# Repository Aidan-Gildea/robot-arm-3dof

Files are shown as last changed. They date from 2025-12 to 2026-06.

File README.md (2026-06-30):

# Hubert — 3-DOF Robotic Manipulator

**Inverse Kinematics–driven motion planning with Python & Arduino, built for ~$100.**

*Designed, programmed, and assembled as a self-directed learning project.*

---

## Demo Videos

| Path Tracing Demo | Hardware Overview | Project Presentation |
|---|---|---|
| Path Tracing (https://youtu.be/4sgCwkX76dg?si=9VvJAM_YSKhd0c1-) | Hardware Overview (https://youtu.be/wcLp37mRvIc?si=lRgipF_aaHsbhIL2) | Project Presentation (https://youtu.be/JEB1u3Z_pXA?si=sM1r-wsa0qPkrcNg) |
| Hubert traces a scripted 3D semi-circle path. | Walk-through of the mechanical and electrical design. | Full project presentation and live demo. |

---

## Project Overview

Hubert is a **3-Degree-of-Freedom (3-DOF) robotic manipulator** capable of precise end-effector positioning from Cartesian coordinate inputs. The arm features three revolute joints (base rotation, shoulder, and elbow) plus a two-finger servo gripper, all driven by a custom **Inverse Kinematics solver that I derived from first principles** using algebra and geometry.

I started this project as a 10th-grade student with almost no prior experience in robotics. I chose to build a manipulator arm because the future of robotics is trending toward humanoid platforms, and an articulated arm is a natural entry point for developing core competencies in mechanical design, embedded systems, and motion planning.

### Barriers Overcome

- **Cost.** The entire project was completed for approximately **$100** in parts and tooling (excluding a 3D printer), making it accessible without institutional funding.
- **Self-taught curriculum.** With no structured coursework available, I taught myself 3D CAD modeling (Fusion 360), electronics (wiring, PWM, I²C), and programming (C++, Python, serial communication) through YouTube tutorials and online documentation—learning as I built.

---

## Bill of Materials

| Category | Component | Function |
|---|---|---|
| Microcontroller | [Arduino Uno R3](https://www.amazon.com/ELEGOO-Board-ATmega328P-ATMEGA16U2-Compliant/dp/B01EWOE0UU) | Low-level control & serial I/O  |
| Actuators | [5× MG996R Servos](https://www.amazon.com/4-Pack-MG996R-Torque-Digital-Helicopter/dp/B07MFK266B) (4-pack + 1) | High-torque joint & gripper actuation |
| Servo Driver | [PCA9685 16-Channel PWM Driver](https://www.amazon.com/HUAREW-PCA9685-Interface-Compatible-Raspberry/dp/B0CRV3MK14) | Dedicated PWM generation via I²C |
| Power Supply | [Adjustable DC Module](https://www.amazon.com/Adjustable-Switching-Regulated-Adjustments-Jesverty/dp/B09YSJQWRG) | Isolated 5–6 V servo power rail |
| Fasteners | [M2.5/M3 Phillips Screws](https://www.amazon.com/NINDEJIN-Countersunk-Replacement-Electronic-Accessories/dp/B0B5CY5LY5) | Structural assembly |
| Fasteners | [M2.5/M3 Threaded Heat-Set Inserts](https://www.amazon.com/Ktehloy-Threaded-Assortment-Printing-Components/dp/B0CLKDPN65)  | Durable screw receptacles in 3D prints |
| Supports | Standard ball bearings | Low-friction joint rotation |

> **Note:** Purchase links are provided for convenience and may expire over time. The full 3D-printable assembly is available at `Hardware/CAD/Full Assembly.step`. A detailed parts list is also in `Hardware/BOM.csv`.

---

## System Architecture

```
┌──────────────────────┐       USB / Serial        ┌──────────────────────┐
│   Host Computer      │      (9600 baud)          │   Arduino Uno        │
│                      │ ─────────────────────────▶ │                      │
│  Python              │   "base j1 j2 g1 g2\n"   │  main.cpp            │
│  ├─ kinematics.py    │                           │  ├─ Serial parser    │
│  ├─ controller.py    │                           │  └─ motors.cpp       │
│  └─ fun_path.py      │                           │      ├─ PCA9685 I²C  │
│                      │                           │      └─ Servo PWM    │
└──────────────────────┘                           └──────────┬───────────┘
                                                              │ I²C
                                                   ┌──────────▼───────────┐
                                                   │  PCA9685 PWM Driver  │
                                                   │  (16 channels)       │
                                                   └──┬──┬──┬──┬──┬──────┘
                                                      │  │  │  │  │
                                                   Servo1─5 (MG996R)
```

The host computer runs the IK solver and sends joint angles over serial. The Arduino parses incoming commands and forwards pulse-width values to the PCA9685, which generates 50 Hz PWM signals for each servo.

---

## Inverse Kinematics

The IK solver lives in `RobotArmKinematics/kinematics.py` and converts a Cartesian target $(x, y, z)$ into three joint angles. This is the core piece of math that makes the arm useful—without it, you would need to manually compute angles for every desired position.

### Arm Geometry

| Parameter | Value |
|---|---|
| Base link height | 50 mm |
| Link 1 (shoulder → elbow) | 110 mm  |
| Link 2 (elbow → end-effector) | 71 mm |
| Max theoretical reach | 181 mm  |
| General servo offset | 60° |

### Algorithm

The solver performs the following steps. All intermediate calculations use radians; outputs are converted to integer degrees.

1. **Subtract base height.** The target $y$ coordinate is reduced by the base link height (50 mm) to shift the origin to the shoulder joint.

2. **Project onto the XZ plane.** Compute the horizontal radius:

$$r = \sqrt{x^2 + z^2}$$

3. **Enforce physical constraints.** Reject the target if $z < 0$ (below the ground plane).

4. **Base rotation angle.** Using the Law of Cosines on the projected circle, compute the base angle relative to the positive X-axis. The angle is then normalized to $[0°, 180°]$ to match servo limits.

5. **Joint 1 (shoulder).** Compute the planar distance from the shoulder to the target:

$$a_3 = \sqrt{x_{\text{proj}}^2 + y_{\text{proj}}^2}$$

Then solve using:

$$\theta_1 = \text{atan2}(y_{\text{proj}},\; x_{\text{proj}}) + \arccos\!\left(\frac{L_1^2 + a_3^2 - L_2^2}{2 \cdot L_1 \cdot a_3}\right) + \text{offset}$$

6. **Joint 2 (elbow).** Apply the Law of Cosines to the triangle formed by $L_1$, $L_2$, and $a_3$:

$$\theta_2 = \arccos\!\left(\frac{L_1^2 + L_2^2 - a_3^2}{2 \cdot L_1 \cdot L_2}\right) - 90° + \text{offset}$$

7. **Clamp and validate.** All three angles are checked against $[0°, 180°]$. If any fall outside this range, the target is deemed unreachable and the function returns `False`.

### Workspace Analysis

The script `RobotArmKinematics/workspace_test.py` performs a brute-force reachability scan over a 3D grid (default step size: 10 mm) and exports all valid $(x, y, z) \rightarrow (\theta_{\text{base}}, \theta_1, \theta_2)$ mappings to `workspace_results.json`. This is useful for visualizing the arm's true working envelope and identifying dead zones.

---

## Software

Hubert's software is split into two layers, mirroring the physical separation between the host computer and the onboard microcontroller.

### Host-Side — Python

The Python programs run on the host computer and handle kinematics, user input, and serial transmission.

| File | Purpose |
|---|---|
| `kinematics.py` | Core IK solver — `IK()` function and `distance_formula()` helper. |
| `controller.py` | **Real-time Pygame controller.** Arrow keys for XY, F/B for Z, Space to toggle gripper, R to home. Includes a rate-limited command loop (50 ms) and a visual GUI overlay. |
| `fun_path.py` | Scripted path demonstration — traces a semi-circle at two heights with smooth transitions. Used in the demo video. |
| `communication.py`  | Minimal serial test — sends a homing command to verify connectivity. |
| `workspace_test.py` | Brute-force 3D reachability scan, exports results to JSON. |

**Controller key bindings:**

| Key | Action |
|---|---|
| ↑ / ↓ | Move Y (vertical) |
| ← / → | Move X (horizontal) |
| F / B | Move Z (depth) |
| Space | Toggle gripper |
| R | Reset to home |
| Esc | Quit |

### Firmware — C++ / PlatformIO

The firmware runs on the Arduino Uno and is managed with [PlatformIO](https://platformio.org/).

| File | Purpose |
|---|---|
| `main.cpp` | Serial read loop — accumulates bytes, tokenizes on spaces, parses 5 integers, dispatches to motor driver. |
| `motors.cpp` | PCA9685 initialization, angle → pulse mapping with per-servo calibration offsets, homing routine, analog feedback reading. |
| `motors.h` | Constants (pulse range 145–560, 50 Hz, channel addresses, per-servo offsets) and function declarations. |
| `communication.cpp`| Legacy text-command parser (SERVO, HOME, HELP, ANGLE). Currently disabled — preserved for future re-integration. |

**Homing behavior:** On startup, all servos are driven to 90° (mid-range). Joints 1 and 2 additionally receive a 60° general offset to position the arm upright, maximizing the usable range of motion.

---

## Getting Started

### Prerequisites

- **Hardware:** Assemble per the BOM above. Wire the PCA9685 to the Arduino via I²C (SDA → A4, SCL → A5). Power servos from the adjustable DC supply (set to 5–6 V), **not** from the Arduino's 5 V rail.
- **Firmware toolchain:** [PlatformIO](https://platformio.org/) (VS Code extension or CLI).
- **Python 3.8+** with `pip`.

### Flash the Firmware

```bash
# From the repository root
pio run --target upload
```

### Install Python Dependencies

```bash
pip install numpy pyserial pygame
```

### Run the Controller

```bash
cd RobotArmKinematics
python controller.py
```

> **Important:** Set the `PORT` variable at the top of the Python script to match your Arduino's COM port (e.g., `COM6` on Windows, `/dev/ttyACM0` on Linux).

---

## Serial Protocol

Commands are sent as **5 space-separated integers** (each 0–180) followed by a newline:

```
90 150 150 50 130\n
```

The five values correspond to: base rotation, joint 1, joint 2, gripper finger A, gripper finger B. The Arduino's 30-byte input buffer supports commands up to 24 characters.

For a detailed walkthrough of the byte-level parsing, tokenization, and execution pipeline, see [PROTOCOL.md](PROTOCOL.md).

---

## Repository Structure

```
robot-arm-3dof/
├── platformio.ini              # PlatformIO build configuration
├── README.md
├── PROTOCOL.md                 # Detailed serial protocol documentation
├── Hardware/
│   ├── BOM.csv                 # Bill of materials with purchase links
│   └── CAD/
│       └── Full Assembly.step  # Complete 3D CAD assembly
├── include/
│   └── motors.h                # Servo constants, channel map, declarations
├── src/
│   ├── main.cpp                # Serial reader and command dispatcher
│   ├── motors.cpp              # PCA9685 driver, homing, offset calibration
│   └── communication.cpp       # Legacy command parser (disabled)
├── RobotArmKinematics/
│   ├── kinematics.py           # Inverse kinematics solver
│   ├── controller.py           # Pygame real-time controller
│   ├── fun_path.py             # Scripted path demonstration
│   ├── communication.py        # Minimal serial connectivity test
│   ├── workspace_test.py       # 3D reachability analysis
│   ├── workspace_results.json  # Exported reachability data
│   └── requirements.txt        # Python dependencies
├── lib/                        # PlatformIO library folder
└── test/                       # PlatformIO test folder
```

---

## Future Work

- **Closed-loop control.** The analog feedback pins (A0–A5) are already wired; implementing PID-based position verification would improve accuracy under load.
- **Computer vision integration.** Object detection via a camera feed to enable autonomous pick-and-place tasks.
- **Re-enable command parser.** Restore the text-based command interface in `communication.cpp` for interactive debugging alongside the IK pipeline.

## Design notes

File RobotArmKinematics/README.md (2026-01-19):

#Kinematics
This the kinematics folder for my project. it contains: 
fun_path.py - a short, ~10 sec demonstration of the robot following a path using my custom Inverse Kinematics function. 
communication.py - a demonstration of sending angle data based off of a single point
kinematics.py - the container for my inverse kinematics function

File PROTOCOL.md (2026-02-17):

# Serial Communication Protocol

The robot arm receives servo angle commands via serial communication at **9600 baud** over USB.

---

## Command Format

Send **5 space-separated integers** (each 0–180) followed by a newline character:

```
base joint1 joint2 gripper1 gripper2\n
```

**Example — home position:**

```
90 150 150 90 90
```

Each integer maps to a servo channel on the PCA9685 driver:

| Position | Servo | PCA9685 Channel | Role |
|---|---|---|---|
| 1 | Base | 0 | Base rotation |
| 2 | Joint 1 | 1 | Shoulder |
| 3 | Joint 2 | 2 | Elbow |
| 4 | Gripper A | 4 | Gripper finger  |
| 5 | Gripper B | 6 | Gripper finger  |

---

## How the Byte Reading Works

The serial reader in `main.cpp` processes incoming bytes one at a time to parse angle commands.

### 1. Byte-by-Byte Accumulation

```cpp
static byte currIndex = 0;   // Persists across loop() calls
char inByte = Serial.read();  // Read one byte at a time
```

Each character is stored in `inputLine[]` until a newline (`\n`) is received:

| Byte # | Character | Buffer State |
|---|---|---|
| 1 | `'9'` | `"9"` |
| 2 | `'0'` | `"90"` |
| 3 | `' '` | `"90 "` |
| 4 | `'4'` | `"90 4"` |
| ... | ... | ... |
| n | `'\n'` | Process! |

### 2. Tokenization

When a newline is received, spaces are replaced with null terminators (`\0`):

```
Before: "90 45 60 30 120\0"
After:  "90\045\060\030\0120\0"
```

This creates **5 separate C-strings** in contiguous memory.

### 3. Parsing

A pointer walks through the buffer, converting each token to an integer:

```cpp
char* ptr = inputLine;
for (int i = 0; i < 5; i++) {
    angles[i] = atoi(ptr);        // Convert string to int
    ptr += strlen(ptr) + 1;       // Jump to next token
}
```

### 4. Execution

The parsed angles are passed to `ServosSetAngles()`, which:

1. **Validates** each angle is within `[0, 180]`.
2. **Maps** each angle to a PWM pulse length using the formula:
   ```
   pulse = map(angle, 0, 180, SERVOMIN, SERVOMAX)
   ```
   where `SERVOMIN = 145` and `SERVOMAX = 560` (out of 4096 ticks at 50 Hz).
3. **Applies** per-servo calibration offsets to compensate for hardware misalignment.
4. **Writes** the final pulse to the corresponding PCA9685 channel via I²C.

---

## Buffer Limits

| Parameter | Value |
|---|---|
| Max input length | 30 bytes |
| Max valid command | `"180 180 180 180 180\n"` = 24 chars  |
| Baud rate | 9600 |
| Line terminator | `\n` (newline) |

---

## Per-Servo Calibration Offsets

Each servo has an individual angular offset defined in `motors.h` to correct for mechanical misalignment:

| Servo | Offset |
|---|---|
| Base | +10° |
| Joint 1 | −10° |
| Joint 2 | −5° |
| Gripper A | +10° |
| Gripper B | −10° |

These offsets are converted from degrees to pulse-length deltas and applied after the angle-to-pulse mapping. Additionally, joints 1 and 2 receive a **general offset of 60°** (converted to pulse length) during the homing routine to increase their effective range of motion.

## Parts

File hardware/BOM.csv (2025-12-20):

Item | Purchase Link
M2.5/M3 Phillips screw kit | https://www.amazon.com/NINDEJIN-Countersunk-Replacement-Electronic-Accessories/dp/B0B5CY5LY5
MG996R servo motors (4-pack) | https://www.amazon.com/4-Pack-MG996R-Torque-Digital-Helicopter/dp/B07MFK266B?sp_csd=d2lkZ2V0TmFtZT1zcF9hdGY
PCA9685 16-channel PWM driver | https://www.amazon.com/HUAREW-PCA9685-Interface-Compatible-Raspberry/dp/B0CRV3MK14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
Adjustable DC power supply module | https://www.amazon.com/Adjustable-Switching-Regulated-Adjustments-Jesverty/dp/B09YSJQWRG?cv_ct_cx=power+supply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
M2.5/M3 threaded heat-set inserts | https://www.amazon.com/Ktehloy-Threaded-Assortment-Printing-Components/dp/B0CLKDPN65
Arduino Uno R3 compatible board | https://www.amazon.com/ELEGOO-Board-ATmega328P-ATMEGA16U2-Compliant/dp/B01EWOE0UU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

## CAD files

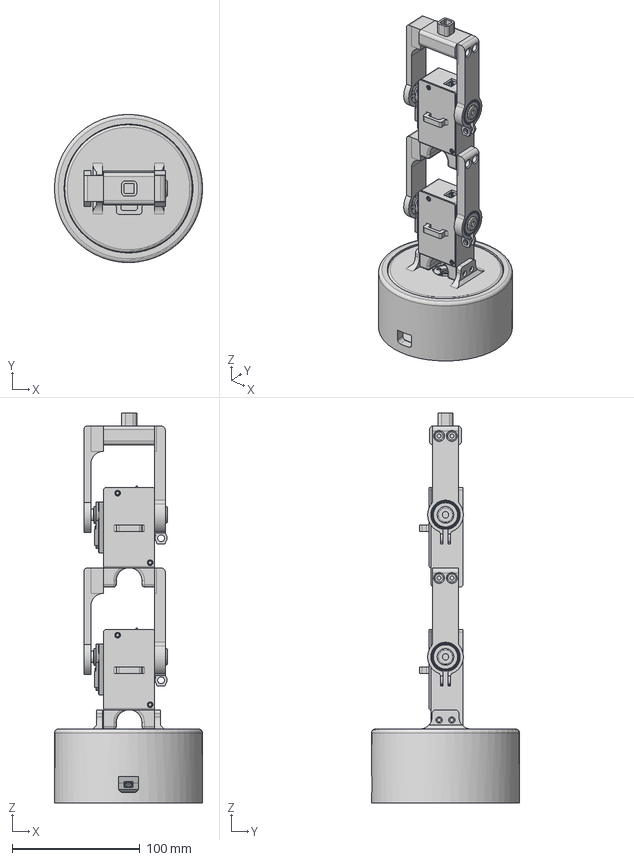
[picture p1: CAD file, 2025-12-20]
hardware/CAD/Full Assembly.step
116.0 x 116.0 x 305.6 mm
arm_round x 3
Mg996r x 3
Main Body x 2
FrontCover x 2
Lid x 2
Inner x 2
Outer x 2
arm1_2 x 2
arm2_2 x 2
BaseCase
BaseLid

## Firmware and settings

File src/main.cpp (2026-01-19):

#include <Wire.h>
#include <Adafruit_PWMServoDriver.h>
// #include <communication.cpp> 
#include "motors.h"

void setup() {

  //beginning serial on Baud 9600
  Serial.begin(9600);

  //motors setup for 5 servos
  setupMotors(5);

  delay(500);
  
  // home servos on startup - not needed every time
  HomeServos();
}


const byte MAX_LEN = 30; // max length in bytes of an input line (increased for 5 motors)
char inputLine[MAX_LEN]; // char array to hold the current input line
int angles[5]; // array to hold parsed angles for 5 motors

void loop() // serial reader
{
  static byte currIndex = 0;
  while(Serial.available() > 0)
  {
    char inByte = Serial.read();
    if(inByte != '\n' && currIndex < MAX_LEN - 1) 
    {
      inputLine[currIndex++] = inByte;
    } 
    else
    {
      inputLine[currIndex] = '\0'; // Null-terminate the string
      for(int i = 0; i < currIndex; i++)
      {
        if(inputLine[i] == ' ')
        {
          inputLine[i] = '\0'; // Replace space with null terminator
        }
      }


      char* ptr = inputLine;
      for (int i = 0; i < 5; i++) {
          angles[i] = atoi(ptr);
          ptr += strlen(ptr) + 1;  // jump past current token and null terminator
      }

      // !!!! do not want to have the IK and this robot both printing onto serial at the same time
      // Serial.print("Angles: ");
      // for (int i = 0; i < 3; i++) {
      //     Serial.print(angles[i]);
      //     if (i < 2) Serial.print(", ");
      // }


      ServosSetAngles(angles);

      for(int i = 0; i < 5; i++)
      {
        angles[i] = 0; // Reset angles after processing
      }

      currIndex = 0; // Reset index for next input
    }
  }

  

}

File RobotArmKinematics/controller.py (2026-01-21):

"""
Robot Arm Controller using Pygame
---------------------------------
Controls:
  Arrow Up/Down   : Move Y axis (vertical)
  Arrow Left/Right: Move X axis (horizontal)
  F / B           : Move Z axis (forward/backward)
  Space           : Toggle gripper (open/close)
  R               : Reset to home position
  ESC             : Quit
"""

# pyright: reportMissingModuleSource=false
# pylint: disable=no-member

import pygame
import time
import kinematics as k

try:
    from serial import Serial, SerialException  # type: ignore
except ImportError:
    print("pyserial not found. Install with: pip install pyserial")
    raise

# --- CONFIGURATION ---
PORT = 'COM6'
BAUD = 9600

# Link lengths in mm
BASE_LINK_LENGTH = 50
L1, L2 = 110, 71
GENERAL_OFFSET = 60

# Movement step size (mm per key press/hold)
STEP_SIZE = 1 

# Starting position (home)
HOME_X, HOME_Y, HOME_Z = 0, 150, 50

# Gripper angles (open and closed)
GRIPPER_OPEN_ANGLES = (50, 130)      # servo4, servo5 angles when open
GRIPPER_CLOSED_ANGLES = (0, 180)    # servo4, servo5 angles when closed

# Position limits (mm)
X_MIN, X_MAX = -150, 150
Y_MIN, Y_MAX = -100, 200
Z_MIN, Z_MAX = 0, 150


class RobotState:
    """Holds the current state of the robot arm."""
    def __init__(self):
        self.x = HOME_X
        self.y = HOME_Y
        self.z = HOME_Z
        self.gripper_closed = True
    
    def reset(self):
        """Reset to home position."""
        self.x = HOME_X
        self.y = HOME_Y
        self.z = HOME_Z
        self.gripper_closed = True


def send_command(ser, state: RobotState):
    """
    Calculate IK and send command to robot arm.
    Returns True if successful, False if position unreachable.
    """
    angles = k.IK(BASE_LINK_LENGTH, L1, L2, state.x, state.y, state.z, GENERAL_OFFSET)
    
    if angles:
        base, j1, j2 = angles
        grip1, grip2 = GRIPPER_CLOSED_ANGLES if state.gripper_closed else GRIPPER_OPEN_ANGLES
        
        message = f"{base} {j1} {j2} {grip1} {grip2}\n"
        ser.write(message.encode('ascii'))
        return True
    return False


def clamp(value, min_val, max_val):
    """Clamp value between min and max."""
    return max(min_val, min(max_val, value))


def main():
    state = RobotState()
    
    # Initialize Pygame
    pygame.init()
    screen = pygame.display.set_mode((400, 300))
    pygame.display.set_caption("Robot Arm Controller")
    clock = pygame.time.Clock()
    font = pygame.font.Font(None, 24)
    
    # Connect to Arduino
    ser = None
    try:
        print(f"Connecting to {PORT}...")
        ser = Serial(PORT, BAUD, timeout=1)
        time.sleep(2)  # Wait for Arduino reset
        print("Connected!")
        
        # Send initial home position
        send_command(ser, state)
        
    except SerialException as e:
        print(f"Error: Could not open {PORT}. {e}")
        pygame.quit()
        return
    
    running = True
    last_send_time = 0
    send_interval = 0.05  # Minimum time between commands (50ms)
    
    print("\n--- Controls ---")
    print("Arrow Up/Down   : Y axis (vertical)")
    print("Arrow Left/Right: X axis (horizontal)")
    print("F / B           : Z axis (forward/backward)")
    print("Space           : Toggle gripper")
    print("R               : Reset to home")
    print("ESC             : Quit\n")
    
    while running:
        position_changed = False
        
        for event in pygame.event.get():
            if event.type == pygame.QUIT:
                running = False
            elif event.type == pygame.KEYDOWN:
                if event.key == pygame.K_ESCAPE:
                    running = False
                elif event.key == pygame.K_SPACE:
                    # Toggle gripper
                    state.gripper_closed = not state.gripper_closed
                    position_changed = True
                    print(f"Gripper: {'CLOSED' if state.gripper_closed else 'OPEN'}")
                elif event.key == pygame.K_r:
                    # Reset to home
                    state.reset()
                    position_changed = True
                    print("Reset to home position")
        
        # Handle continuous key presses for movement
        keys = pygame.key.get_pressed()
        
        # Y axis (Up/Down arrows)
        if keys[pygame.K_UP]:
            state.y = clamp(state.y + STEP_SIZE, Y_MIN, Y_MAX)
            position_changed = True
        if keys[pygame.K_DOWN]:
            state.y = clamp(state.y - STEP_SIZE, Y_MIN, Y_MAX)
            position_changed = True
            
        # X axis (Left/Right arrows)
        if keys[pygame.K_LEFT]:
            state.x = clamp(state.x + STEP_SIZE, X_MIN, X_MAX)
            position_changed = True
        if keys[pygame.K_RIGHT]:
            state.x = clamp(state.x - STEP_SIZE, X_MIN, X_MAX)
            position_changed = True
            
        # Z axis (F/B keys)
        if keys[pygame.K_f]:
            state.z = clamp(state.z + STEP_SIZE, Z_MIN, Z_MAX)
            position_changed = True
        if keys[pygame.K_b]:
            state.z = clamp(state.z - STEP_SIZE, Z_MIN, Z_MAX)
            position_changed = True
        
        # Send command if position changed (with rate limiting)
        current_time = time.time()
        if position_changed and (current_time - last_send_time) >= send_interval:
            success = send_command(ser, state)
            if not success:
                print(f"Warning: Position ({state.x}, {state.y}, {state.z}) unreachable")
            last_send_time = current_time
        
        # --- Draw UI ---
        screen.fill((30, 30, 40))
        
        # Title
        title = font.render("Robot Arm Controller", True, (255, 255, 255))
        screen.blit(title, (120, 20))
        
        # Position display
        pos_text = font.render(f"Position: X={state.x:6.1f}  Y={state.y:6.1f}  Z={state.z:6.1f}", True, (200, 200, 200))
        screen.blit(pos_text, (50, 60))
        
        # Gripper status
        grip_color = (255, 100, 100) if state.gripper_closed else (100, 255, 100)
        grip_text = font.render(f"Gripper: {'CLOSED' if state.gripper_closed else 'OPEN'}", True, grip_color)
        screen.blit(grip_text, (140, 90))
        
        # Controls help
        controls = [
            "Controls:",
            "  ↑/↓  : Y axis (up/down)",
            "  ←/→  : X axis (left/right)",
            "  F/B  : Z axis (forward/back)",
            "  Space: Toggle gripper",
            "  R    : Reset to home",
            "  ESC  : Quit"
        ]
        for i, line in enumerate(controls):
            text = font.render(line, True, (150, 150, 150))
            screen.blit(text, (50, 130 + i * 22))
        
        pygame.display.flip()
        clock.tick(70)  # 60 FPS for smooth response
    
    # Cleanup
    if ser and ser.is_open:
        ser.close()
        print("Serial connection closed.")
    pygame.quit()
    print("Controller stopped.")


if __name__ == "__main__":
    main()

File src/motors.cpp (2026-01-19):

#include <Arduino.h>
#include <Adafruit_PWMServoDriver.h>
#include "motors.h"


int NUM_SERVOS;
Adafruit_PWMServoDriver pwm;
// maps offsets from degrees to pulse lengths

const int GENERAL_PULSE_OFFSET = map(SERVO_ANGLE_OFFSET,0,180,0,SERVOMAX-SERVOMIN);

const int SERVO1_PULSE_OFFSET = map(SERVO1_ANGLE_OFFSET,-90,90,-(SERVOMAX-SERVOMIN)/2, (SERVOMAX-SERVOMIN)/2);
const int SERVO2_PULSE_OFFSET = map(SERVO2_ANGLE_OFFSET,-90,90,-(SERVOMAX-SERVOMIN)/2, (SERVOMAX-SERVOMIN)/2);
const int SERVO3_PULSE_OFFSET = map(SERVO3_ANGLE_OFFSET,-90,90,-(SERVOMAX-SERVOMIN)/2, (SERVOMAX-SERVOMIN)/2);
const int SERVO4_PULSE_OFFSET = map(SERVO4_ANGLE_OFFSET,-90,90,-(SERVOMAX-SERVOMIN)/2, (SERVOMAX-SERVOMIN)/2);
const int SERVO5_PULSE_OFFSET = map(SERVO5_ANGLE_OFFSET,-90,90,-(SERVOMAX-SERVOMIN)/2, (SERVOMAX-SERVOMIN)/2);

const int DEGREE_90_PULSE = SERVOMIN + (SERVOMAX - SERVOMIN) / 2; // 90 degrees pulse length

// Arrays for easy iteration

const int SERVO_ADDRESSES[NUM_MOTORS] = {SERVO1_ADDRESS, SERVO2_ADDRESS, SERVO3_ADDRESS, SERVO4_ADDRESS, SERVO5_ADDRESS};
const int SERVO_PULSE_OFFSETS[NUM_MOTORS] = {SERVO1_PULSE_OFFSET, SERVO2_PULSE_OFFSET, SERVO3_PULSE_OFFSET, SERVO4_PULSE_OFFSET, SERVO5_PULSE_OFFSET};


void setupMotors(int servoAmount)
{
  NUM_SERVOS = servoAmount;
  pwm = Adafruit_PWMServoDriver();
  pwm.begin(); // very important to call this function!!
  pwm.setPWMFreq(SERVO_FREQ);

  // setup for feedback pins
  for (int i = 0; i < servoAmount && i < 6; i++) {
      pinMode(A0 + i, INPUT); // A0, A1, etc. are sequential constants
  }
}

//later on I want to improve this function by taking in an angle from the rotary encoder and using it to find how to time to slow down speed. 
bool ServosSetAngles(int args[])
{
  // Check inputs are within bounds
  for(int i = 0; i < NUM_MOTORS; i++) {
    if (args[i] < 0 || args[i] > 180) {
      return false;
    }
  }

  // Map angles to pulse lengths and send to PCA9685 using custom addresses
  for(int i = 0; i < NUM_MOTORS; i++) {
    int pulse = map(args[i], 0, 180, SERVOMIN, SERVOMAX);
    // in this case pulse represents the angle converted to pulse length

    pwm.setPWM(SERVO_ADDRESSES[i], 0, pulse + SERVO_PULSE_OFFSETS[i]);
  }

  return true;
}


// }

// bool ServoSetAngle(String args)
// {
//   args.trim();
//   int space = args.indexOf(' ');
//   if(space == -1)
//   {
//     Serial.println("Incorrect Inputs for SERVO");
//   }
//   else
//   {
//     Serial.println("Moving SERVO " + args);
//   }

//   byte servoIndex = args.substring(0, space).toInt();
//   float angle = args.substring(space + 1).toFloat();
//   Serial.println();


//   if(servoIndex >= NUM_SERVOS || servoIndex < 0) return false;
//   if(angle > 180 || angle < 0) return false;
//   int pulseLength = map(angle, 0, 180, SERVOMIN, SERVOMAX);
//   pwm.setPWM(servoIndex, 0, pulseLength);
//   return true;

// }

void HomeServos()
{
  // optional message for debugging
  //Serial.println("Homing all servos to straight position. ");
  
  int degrees = (SERVOMAX - SERVOMIN) / 2 + SERVOMIN; // 90 degrees for all

  Serial.println(degrees);
  
  // Home first servo without general offset (base rotation)
  pwm.setPWM(SERVO_ADDRESSES[0], 0, DEGREE_90_PULSE + SERVO_PULSE_OFFSETS[0]); 
  
  // Home remaining servos with general offset
  for(int i = 1; i < 3; i++) {
    pwm.setPWM(SERVO_ADDRESSES[i], 0, DEGREE_90_PULSE + SERVO_PULSE_OFFSETS[i] + GENERAL_PULSE_OFFSET);
  }
  for(int i = 3; i < NUM_MOTORS; i++) {
    pwm.setPWM(SERVO_ADDRESSES[i], 0, DEGREE_90_PULSE + SERVO_PULSE_OFFSETS[i]); // since only the 1 and 2 servos need general pulse offset
  }
}

float PrintServoAngle(String index) ///always returns integer angle, I wonder why that is :/
{
  Serial.println("Angle is: ");
  int servoIndex = index.toInt();

  if(servoIndex >= NUM_SERVOS || servoIndex < 0) return -1;

  return (map(analogRead(A0+servoIndex), 104, 662, 0, 18000)/100.00);

}

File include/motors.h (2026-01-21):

#pragma once
#include <Arduino.h>
#include <Adafruit_PWMServoDriver.h>

// Servo min and max pulse lengths
#define SERVOMIN  145  // Minimum pulse length (out of 4096)
#define SERVOMAX  560  // Maximum pulse length (out of 4096)
#define SERVO_FREQ 50  // Servo frequency (50Hz for most analog servos) -> Is a constant suggested by library
#define SERVO_ANGLE_OFFSET 60 // The two main joint servos are offset by 60 degrees for more ROM
#define NUM_MOTORS 5  // Number of motors in the system

// Custom PWM channel addresses for each servo (0-15 on PCA9685)
#define SERVO1_ADDRESS 0
#define SERVO2_ADDRESS 1
#define SERVO3_ADDRESS 2
#define SERVO4_ADDRESS 4 // the last two motors control the gripper
#define SERVO5_ADDRESS 6 // the last two motors control the gripper

// Individual servo angle offsets to account for any hardware misalignment
#define SERVO1_ANGLE_OFFSET 10
#define SERVO2_ANGLE_OFFSET -10
#define SERVO3_ANGLE_OFFSET -5
#define SERVO4_ANGLE_OFFSET 10
#define SERVO5_ANGLE_OFFSET -10

extern int NUM_SERVOS;
extern Adafruit_PWMServoDriver pwm;

void setupMotors(int servoAmount);
bool ServosSetAngles(int args[]);
bool ServoSetAngle(String args);
void HomeServos();
float PrintServoAngle(String index);

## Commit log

2025-12-20 Added homing of servos as default sequence when robot is started.
2025-12-20 Pushed purchase links and assembly files + new directory (hardware/CAD)
    [BOM.csv, Full Assembly.f3z, Full Assembly.step]
2025-12-31 Updated comments and refined code, cut repetitive or unnecessary comments
2025-12-31 Cleaned up homing code / variables, implmeneted individual servo angle offsets
2025-12-31 Fixed a bug in my servossetangle function
    [motors.cpp]
2026-01-01 Imported the Kinematics from other repository
2026-01-01 Updated CAD Files
    [Full Assembly.f3z]
2026-01-19 Made code for gripper functionality
2026-01-20 Implemented arm controller, added gripper support, fixed some mechanical issues.
    [communication.py, controller.py, motors.h]
2026-02-17 Update README with latest demo video link
    Added a link to the most recent demo video of the robotic arm.
